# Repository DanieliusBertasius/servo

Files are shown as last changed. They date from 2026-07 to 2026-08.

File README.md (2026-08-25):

# ❗ Servo failed right after testing, suspected potentiometer wearout

Features:
* 5.75 - 12 V input
* Stall detection at 0.8 A
* Saving last servo position in flash on power down

Notes to future self:
* Add ground test points
* Use countersunk screws if screw heads mount on bottom layer, no supports needed
* Use connectors for buttons

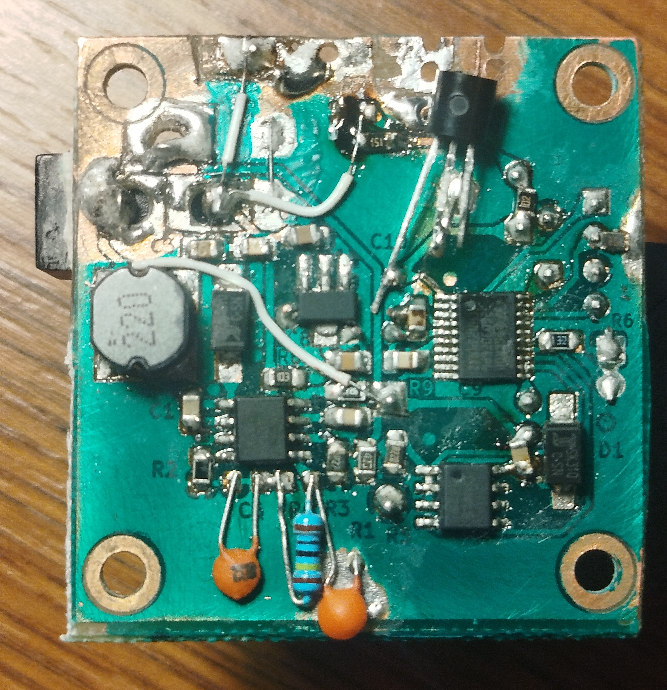
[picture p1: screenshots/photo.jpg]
Finished PCB photo


PSU: <br><br>
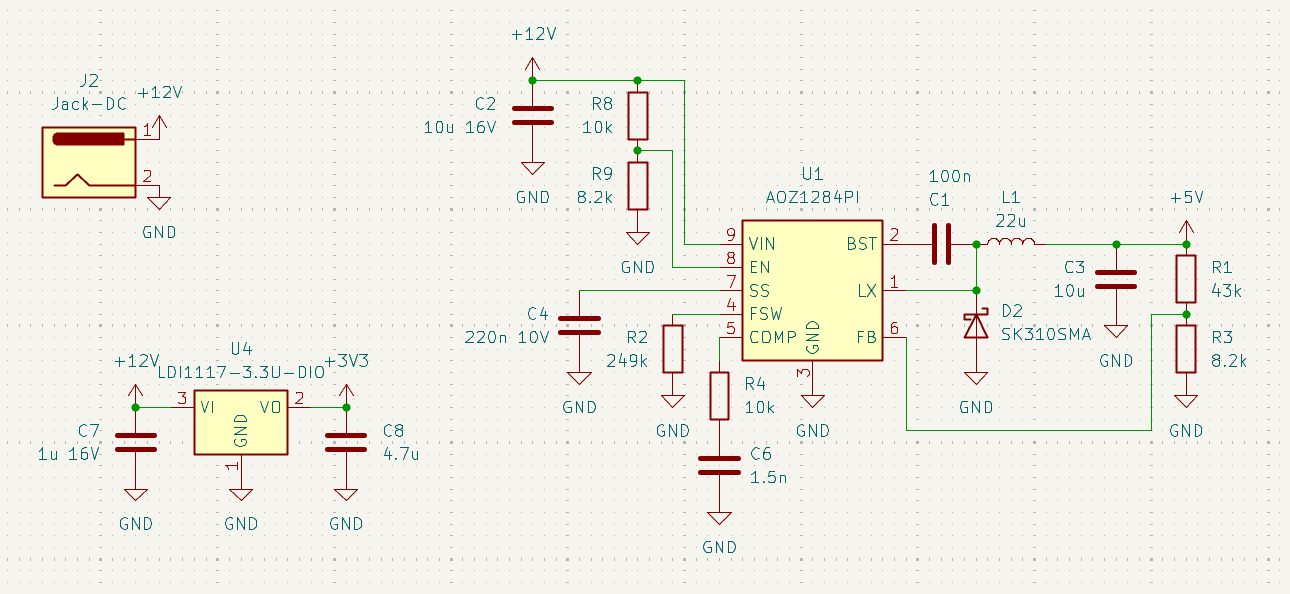
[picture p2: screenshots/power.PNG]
Power schematic


MCU: <br><br>
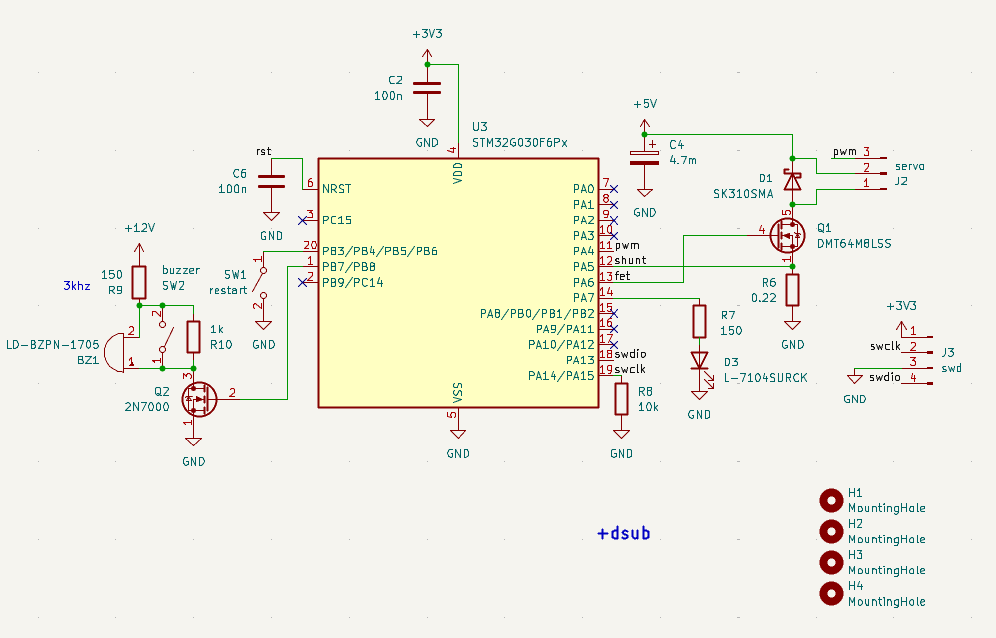
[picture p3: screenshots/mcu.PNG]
MCU schematic

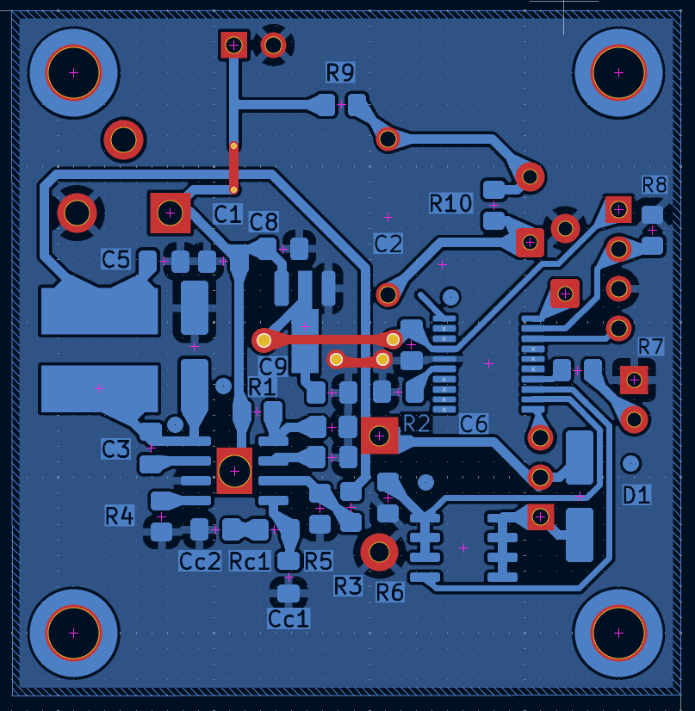
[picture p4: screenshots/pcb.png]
PCB

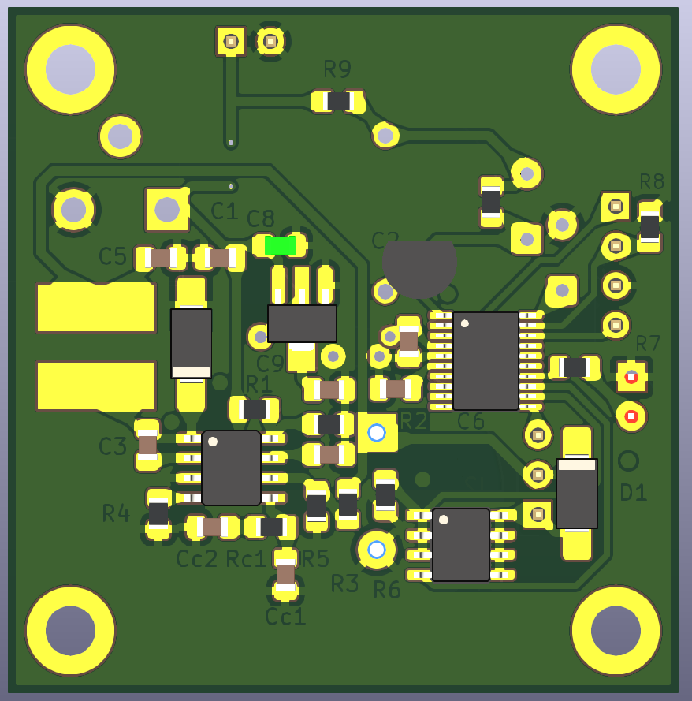
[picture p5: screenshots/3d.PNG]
3D view

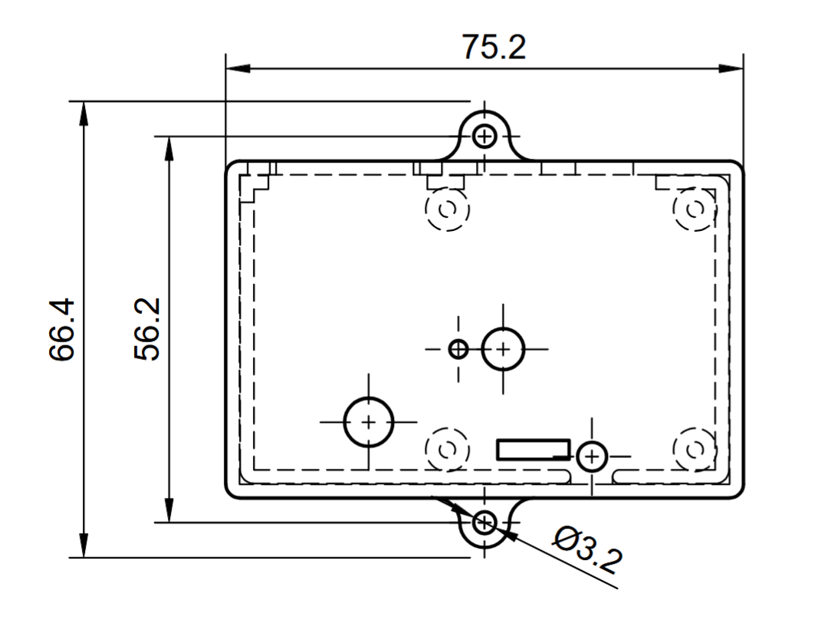
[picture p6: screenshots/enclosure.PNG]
enclosure drawing


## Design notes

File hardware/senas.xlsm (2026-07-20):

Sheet: User Guide
 | EZbuck Design Sheet Directions |  |  | Rev.1.0
The spreadsheet was design to help quickly implement the AOZ1284PI EZbuck controllers in a DC/DC converter using a buck converter.
The spreadsheet requires Iteration to be enabled to operate correctly.This is done through"Tools/Options/Calculation, select "Iteration", set the "Maximum iteration" to"1000" and the "Maximum change" to"0.0001".
The design tool will generate a recommended design that includes the loop compensation parameters and the calculated efficiency.The recommended values in the design may not be practical, yet the operation of the converter can be altered by using the closest parameter.
Input converter parameters: |  | Select buck regulator IC: | Pick the IC you want to design with.
 |  | Input voltage: | Which is converter input voltage.
 |  | Output voltage: | Which is converter output voltage.
 |  | Maximum output current: | Which is converter maximum output current.
 |  | Maximum output voltage ripple%: | Which is the output voltage ripple ratio.
 |  | Ambient temperature: | Which is the converter ambient temperature.
To use the design tool, enter data in the cells with the yellow text, the calculated values are in the cells with blue text. Red font indicate illegal input or potential design problems.

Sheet: EZBuck design calculator
7
EZBuck Design Spreadsheet |  | Rev. 1.0
Yellow cell | is the input parameters
Blue cell | is the calculated parameters
 | is the cell with comment |  | Step1: Buck regulator IC selection
 |  |  | 4
Typical application schematic
 |  |  | Step2: Define the system specification
 |  |  | Enter Application Parameters
 |  |  | Input Voltage: | 12 | V
 |  |  | Output Voltage: | 5 | V
 |  |  | Maximum Output Current: | 0.8 | A
 |  |  | Maximum Output Voltage Ripple%: | 3 | %
 |  |  | Ambient Temperature | 25 | ℃
 |  |  | Step3: RF selection
 |  |  | Switching Frequency needed: | 200 | kHz
 |  |  | Rcommend value for RF : | 250 | kΩ
 |  |  | Step4: Power stage component selection
 |  |  | Inductor Selection (L1)
 |  |  | Recommended L: | 10.42 | µH
 |  |  | Recommended ISATURATE: | 6.00 | A
 |  |  | Enter The Chosen Inductor Value: | 22 | µH
 |  |  | Enter The DCR of Chosen Inductor: | 100 | mΩ
 |  |  | Diode Selection (D1)
 |  |  | Enter The Diode Saturation Voltage: | 0.4 | V
Calculated Efficiency vs Load Current |  |  | Capacitor Selection (CIN and CO)
 |  |  | Minimum Recommended Input Capacitance: | 22 | µF
 |  |  | Minimum Input Capacitor RMS current rating: | 0.39 | Arms
 |  |  | Minimum Recommended Output Capacitance: | 2.761994949 | µF
 |  |  | Maximum Output Capacitor ESR: | 226.2857143 | mΩ
 |  |  | Enter The chosen Output Capacitor Value: | 1500 | µF
 |  |  | Enter The chosen Output Capacitor ESR: | 177 | mΩ
 |  |  | Output Voltage Characteristics
 |  |  | Estimated Output Voltage Ripple: | 117.6057449 | mV
 |  |  | Step5: Control component selection
 |  |  | Feedback Resistors Selection(RFB1, RFB2)
 |  |  | Enter a Value for RFB2: | 10 | kΩ
 |  |  | Recommended Value for RFB1: | 52.5 | kΩ
 |  |  | Compensation Component Selection (RC, CC1, CC2)
 |  |  | Enter Desired Crossover Frequency: | 20 | kHz
Calculated Bode Plot |  |  | Recommended Value for CC1: | 2.704275495 | nF
 |  |  | Recommended Value for RC: | 963.2012175 | kΩ
 |  |  | Recommended Value for CC2: | 265.6433393 | pF
 |  |  | Recommend Value for Cfeedforward: | 218.5731909 | pF
 |  |  | Enter The Chosen Value for CC1: | 2.7 | nF
 |  |  | Enter The Chosen Value for RC: | 963 | kΩ
 |  |  | Enter The Chosen Value for CC2: | 265 | pF
 |  |  | Enter The Chosen Value for Cfeedforward: | 220 | pF
 |  |  | Loop Characteristics
 |  |  | Expected Crossover Frequency: | 34.674 | kHz
 |  |  | Expected Phase Margin: | 70.22653881 | °
 |  |  | Step6: Thermal Performance
 |  |  | Thermal Characteristics
 |  |  | Internal Power Dissipation: | 0.04050994562 | W
 |  |  | Junction Temperature: | 27.51161663 | ℃
 |  |  | For datasheets,evaluation note,please visit: www.aosmd.com (http://www.aosmd.com/web/products/poweric.jsp)

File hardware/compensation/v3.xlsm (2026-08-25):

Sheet: User Guide
 | EZbuck Design Sheet Directions |  |  | Rev.1.0
The spreadsheet was design to help quickly implement the AOZ1284PI EZbuck controllers in a DC/DC converter using a buck converter.
The spreadsheet requires Iteration to be enabled to operate correctly.This is done through"Tools/Options/Calculation, select "Iteration", set the "Maximum iteration" to"1000" and the "Maximum change" to"0.0001".
The design tool will generate a recommended design that includes the loop compensation parameters and the calculated efficiency.The recommended values in the design may not be practical, yet the operation of the converter can be altered by using the closest parameter.
Input converter parameters: |  | Select buck regulator IC: | Pick the IC you want to design with.
 |  | Input voltage: | Which is converter input voltage.
 |  | Output voltage: | Which is converter output voltage.
 |  | Maximum output current: | Which is converter maximum output current.
 |  | Maximum output voltage ripple%: | Which is the output voltage ripple ratio.
 |  | Ambient temperature: | Which is the converter ambient temperature.
To use the design tool, enter data in the cells with the yellow text, the calculated values are in the cells with blue text. Red font indicate illegal input or potential design problems.

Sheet: EZBuck design calculator
7
EZBuck Design Spreadsheet |  | Rev. 1.0
Yellow cell | is the input parameters
Blue cell | is the calculated parameters
 | is the cell with comment |  | Step1: Buck regulator IC selection
 |  |  | 4
Typical application schematic
 |  |  | Step2: Define the system specification
 |  |  | Enter Application Parameters
 |  |  | Input Voltage: | 12 | V
 |  |  | Output Voltage: | 6 | V
 |  |  | Maximum Output Current: | 0.8 | A
 |  |  | Maximum Output Voltage Ripple%: | 3 | %
 |  |  | Ambient Temperature | 25 | ℃
 |  |  | Step3: RF selection
 |  |  | Switching Frequency needed: | 200 | kHz
 |  |  | Rcommend value for RF : | 250 | kΩ
 |  |  | Step4: Power stage component selection
 |  |  | Inductor Selection (L1)
 |  |  | Recommended L: | 10.71 | µH
 |  |  | Recommended ISATURATE: | 6.00 | A
 |  |  | Enter The Chosen Inductor Value: | 22 | µH
 |  |  | Enter The DCR of Chosen Inductor: | 100 | mΩ
 |  |  | Diode Selection (D1)
 |  |  | Enter The Diode Saturation Voltage: | 0.4 | V
Calculated Efficiency vs Load Current |  |  | Capacitor Selection (CIN and CO)
 |  |  | Minimum Recommended Input Capacitance: | 22 | µF
 |  |  | Minimum Input Capacitor RMS current rating: | 0.40 | Arms
 |  |  | Minimum Recommended Output Capacitance: | 2.367424242 | µF
 |  |  | Maximum Output Capacitor ESR: | 264 | mΩ
 |  |  | Enter The chosen Output Capacitor Value: | 4700 | µF
 |  |  | Enter The chosen Output Capacitor ESR: | 1 | mΩ
 |  |  | Output Voltage Characteristics
 |  |  | Estimated Output Voltage Ripple: | 0.7724854932 | mV
 |  |  | Step5: Control component selection
 |  |  | Feedback Resistors Selection(RFB1, RFB2)
 |  |  | Enter a Value for RFB2: | 10 | kΩ
 |  |  | Recommended Value for RFB1: | 65 | kΩ
 |  |  | Compensation Component Selection (RC, CC1, CC2)
 |  |  | Enter Desired Crossover Frequency: | 10 | kHz
Calculated Bode Plot |  |  | Recommended Value for CC1: | 6.477084914 | nF
 |  |  | Recommended Value for RC: | 1369.868621 | kΩ
 |  |  | Recommended Value for CC2: | 0 | pF
 |  |  | Recommend Value for Cfeedforward: | 925.624807 | pF
 |  |  | Enter The Chosen Value for CC1: | 6.8 | nF
 |  |  | Enter The Chosen Value for RC: | 1000 | kΩ
 |  |  | Enter The Chosen Value for CC2: | 0 | pF
 |  |  | Enter The Chosen Value for Cfeedforward: | 0 | pF
 |  |  | Loop Characteristics
 |  |  | Expected Crossover Frequency: | 7.2444 | kHz
 |  |  | Expected Phase Margin: | 55.82813413 | °
 |  |  | Step6: Thermal Performance
 |  |  | Thermal Characteristics
 |  |  | Internal Power Dissipation: | 0.04344546519 | W
 |  |  | Junction Temperature: | 27.69361884 | ℃
 |  |  | For datasheets,evaluation note,please visit: www.aosmd.com (http://www.aosmd.com/web/products/poweric.jsp)

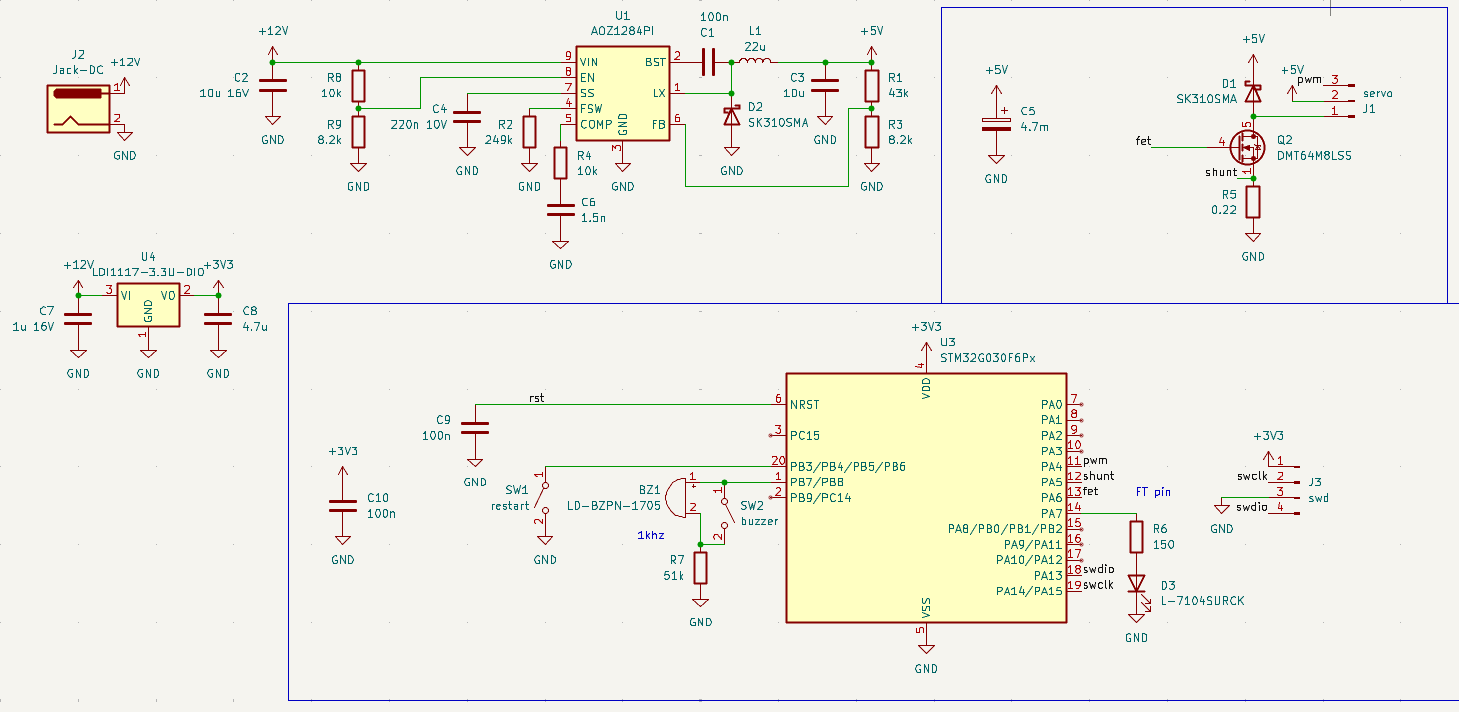
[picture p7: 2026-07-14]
hardware/schematic.png

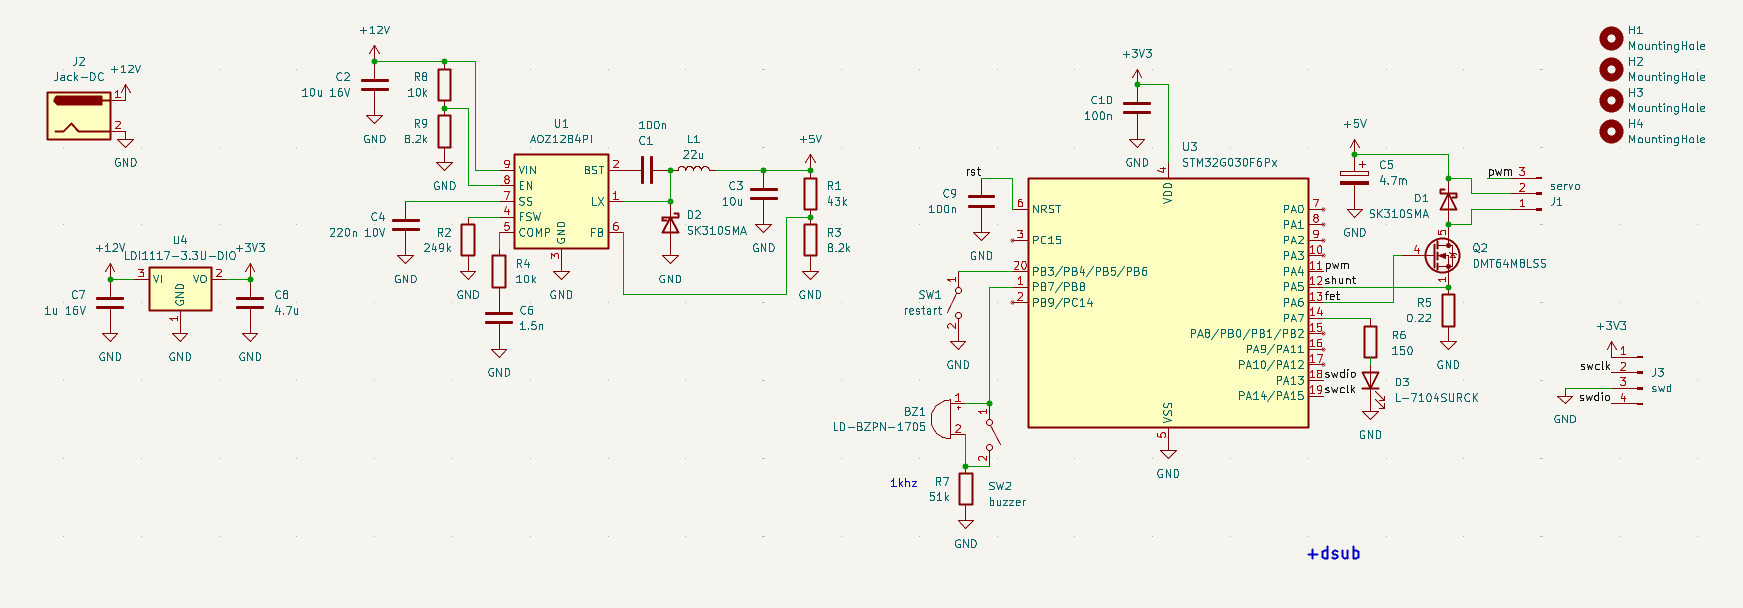
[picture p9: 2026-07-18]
screenshots/schematic.png

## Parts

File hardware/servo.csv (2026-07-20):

Id | Designator | Footprint | Quantity | Designation
1 | BZ1 | LOUDITY LD-BZPN-1705 | 1 | LD-BZPN-1705
2 | C1, C9, C10 | C_0805_2012Metric_Pad1.18x1.45mm_HandSolder | 3 | 100n
3 | C2 | C_0805_2012Metric_Pad1.18x1.45mm_HandSolder | 1 | 10u 16V
4 | C3 | C_0805_2012Metric_Pad1.18x1.45mm_HandSolder | 1 | 10u
5 | C4 | C_0805_2012Metric_Pad1.18x1.45mm_HandSolder | 1 | 220n 10V
6 | C5 | CP_Radial_D16.0mm_P7.50mm | 1 | 4.7m
7 | C6 | C_0805_2012Metric_Pad1.18x1.45mm_HandSolder | 1 | 1.5n
8 | C7 | C_0805_2012Metric_Pad1.18x1.45mm_HandSolder | 1 | 1u 16V
9 | C8 | C_0805_2012Metric_Pad1.18x1.45mm_HandSolder | 1 | 4.7u
10 | D1, D2 | D_SMA_Handsoldering | 2 | SK310SMA
11 | D3 | LED_D3.0mm | 1 | L-7104SURCK
12 | J1 | PinHeader_1x03_P2.54mm_Vertical | 1 | servo
13 | J2 | BarrelJack_CUI_PJ-102AH_Horizontal | 1 | Jack-DC
14 | J3 | PinHeader_1x04_P2.54mm_Vertical | 1 | swd
15 | L1 | LD2-220-HV | 1 | 22u
16 | Q2 | SOIC-8_3.9x4.9mm_P1.27mm | 1 | DMT64M8LSS
17 | R1 | R_0805_2012Metric_Pad1.20x1.40mm_HandSolder | 1 | 43k
18 | R2 | R_0805_2012Metric_Pad1.20x1.40mm_HandSolder | 1 | 249k
19 | R3, R9 | R_0805_2012Metric_Pad1.20x1.40mm_HandSolder | 2 | 8.2k
20 | R4, R8 | R_0805_2012Metric_Pad1.20x1.40mm_HandSolder | 2 | 10k
21 | R5 | R_0805_2012Metric_Pad1.20x1.40mm_HandSolder | 1 | 0.22
22 | R6 | R_0805_2012Metric_Pad1.20x1.40mm_HandSolder | 1 | 1.3k
23 | R7 | R_0805_2012Metric_Pad1.20x1.40mm_HandSolder | 1 | 51k
24 | SW1 | SolderWire-0.25sqmm_1x02_P4.2mm_D0.65mm_OD1.7mm | 1 | restart
25 | SW2 | SolderWire-0.25sqmm_1x02_P4.2mm_D0.65mm_OD1.7mm | 1 | buzzer
26 | U1 | SOIC-8-1EP_3.9x4.9mm_P1.27mm_EP2.71x3.7mm | 1 | AOZ1284PI
27 | U3 | TSSOP-20_4.4x6.5mm_P0.65mm | 1 | STM32G030F6Px
28 | U4 | SOT-89-3_Handsoldering | 1 | LDI1117-3.3U-DIO

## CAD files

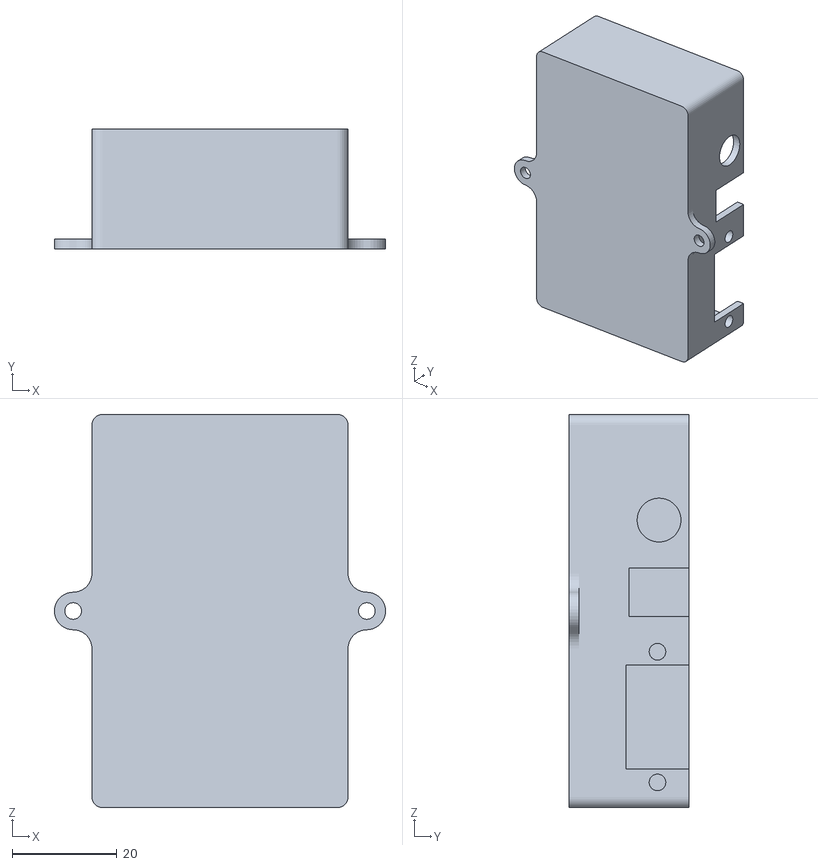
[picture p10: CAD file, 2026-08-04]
hardware/3D/bottom.stl
63.4 x 23.0 x 75.2

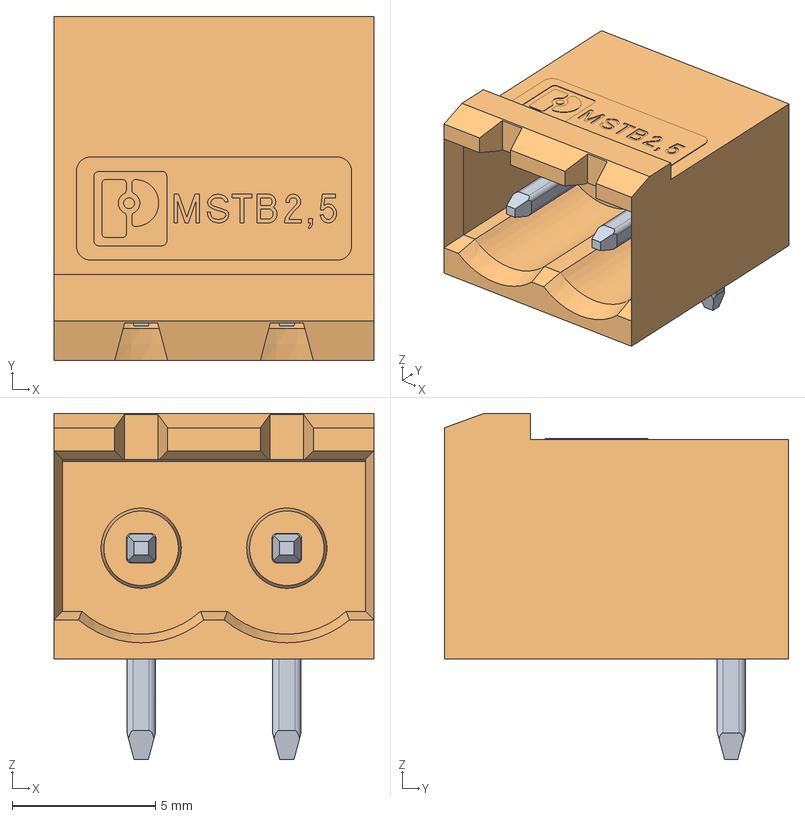
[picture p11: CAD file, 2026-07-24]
hardware/3D/for fusion assembly/terminal.step
11.2 x 12.0 x 12.1 mm

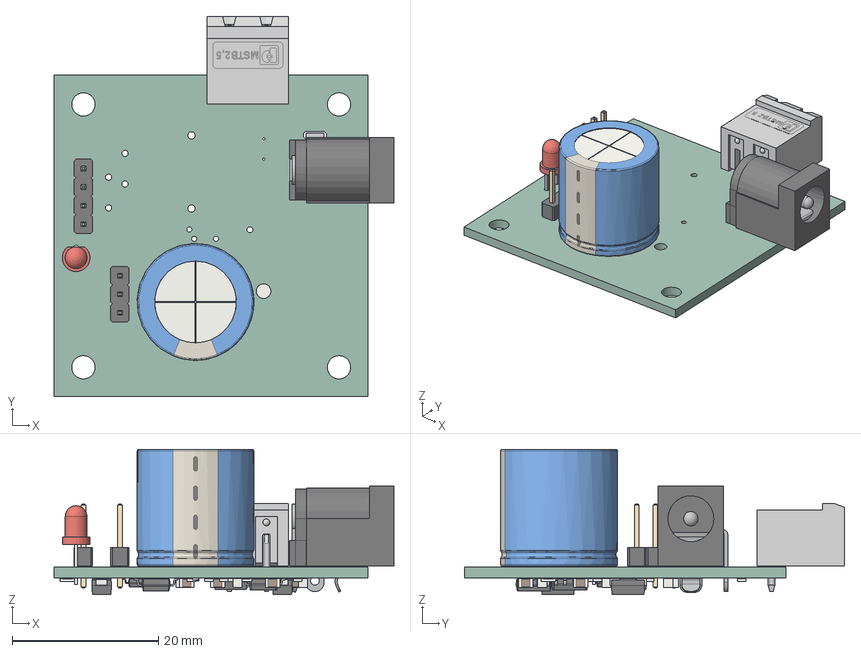
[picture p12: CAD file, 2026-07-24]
hardware/3D/for fusion assembly/pcb.step
46.5 x 52.0 x 19.9 mm
(Unsaved)
LED_D3.0mm
CP_Radial_D160mm_P750mm
PinHeader_1x04_P254mm_Vertical
PinHeader_1x03_P254mm_Vertical
BarrelJack_GCT_DCJ200-10-A_Horizontal
C_0805_2012Metric x 10
R_0805_2012Metric x 10
adbeea57-9c39-11ed-93f0-dde97e994e83_part
adbeea58-9c39-11ed-93f0-dde97e994e83_part
adbeea59-9c39-11ed-93f0-dde97e994e83_part
SOIC-8-1EP_3.9x4.9mm_P1.27mm_EP2.29x3mm
D_SMA x 2
TSSOP-20_4.4x6.5mm_P0.65mm
SOIC-8_3.9x4.9mm_P1.27mm
servo_PCB

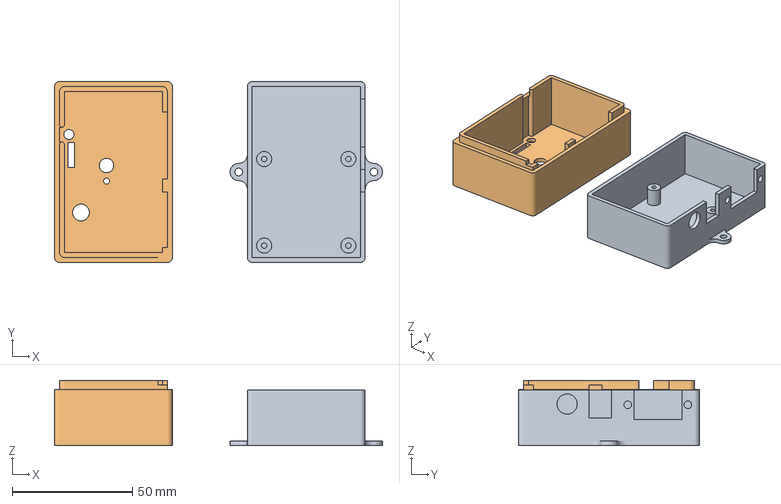
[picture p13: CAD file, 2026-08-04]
hardware/3D/servo_e3v2.3mf
136.4 x 75.2 x 27.1 mm
bottom.stl
top.stl

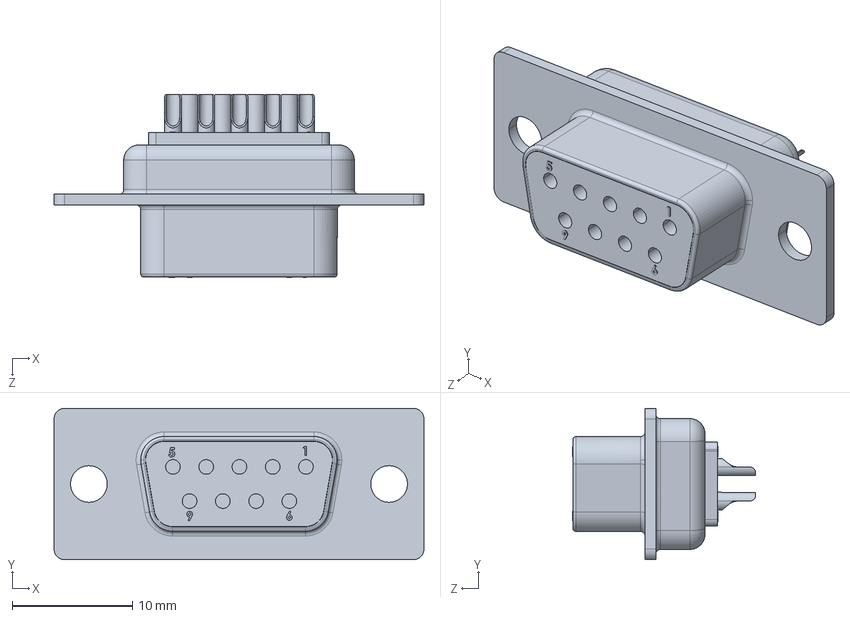
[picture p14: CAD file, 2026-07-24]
hardware/3D/for fusion assembly/dsub.STEP
30.8 x 12.6 x 15.3 mm

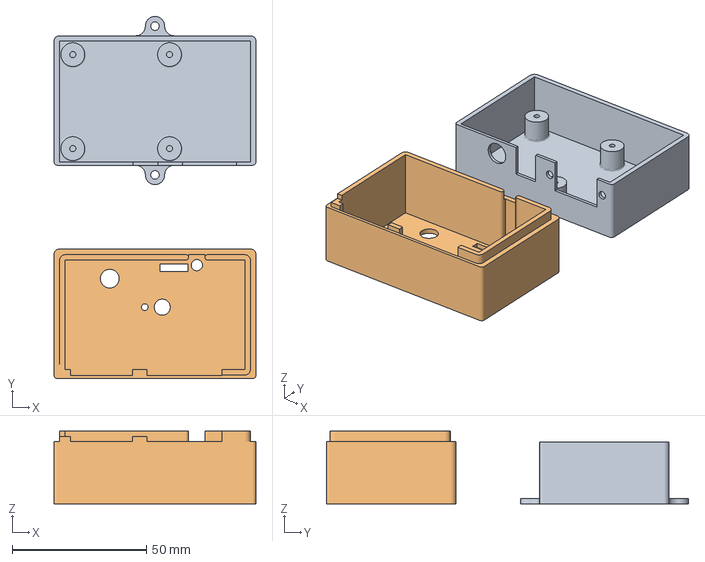
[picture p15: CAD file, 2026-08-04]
hardware/3D/servo_bambu.3mf
75.2 x 134.8 x 27.1 mm
bottom.stl
top.stl

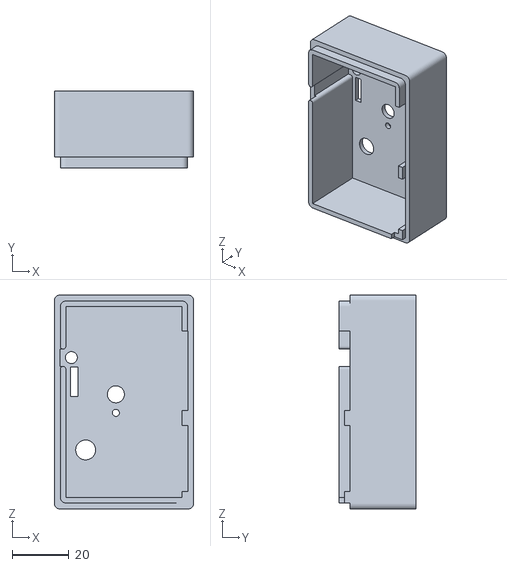
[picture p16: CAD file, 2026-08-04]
hardware/3D/top.stl
49.0 x 27.1 x 75.2

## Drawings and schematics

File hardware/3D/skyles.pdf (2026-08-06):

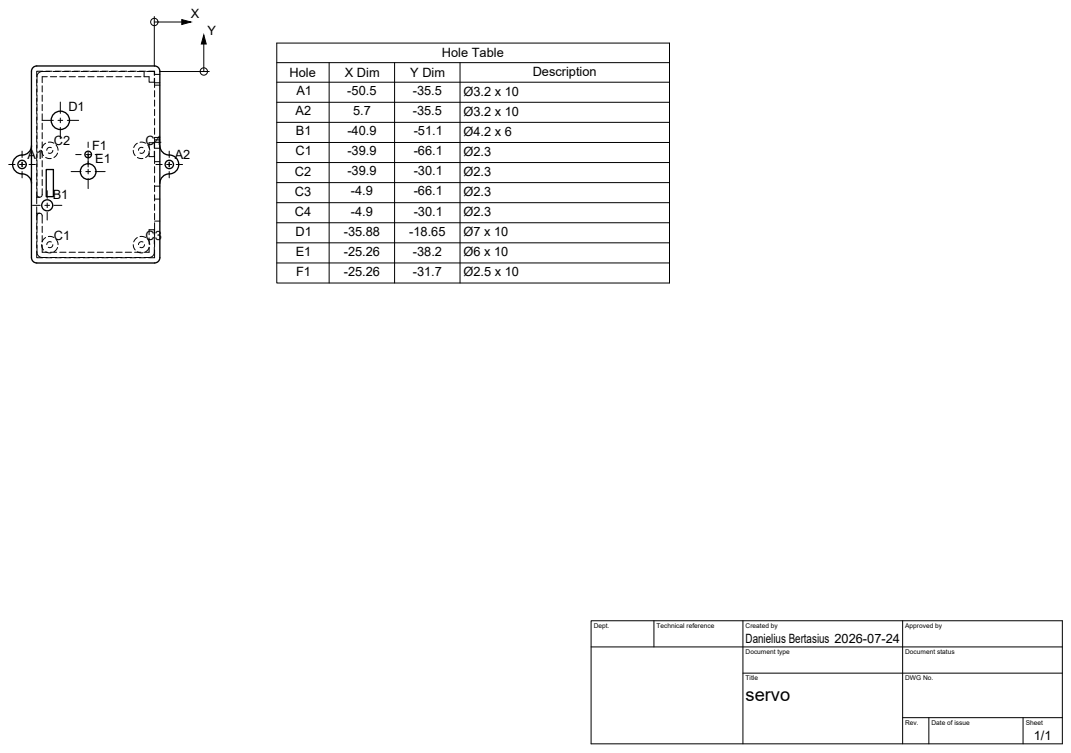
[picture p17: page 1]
Hole Table

Hole | X Dim | Y Dim | Description
A1 | -50.5 | -35.5 | Ø3.2 x 10
A2 | 5.7 | -35.5 | Ø3.2 x 10
B1 | -40.9 | -51.1 | Ø4.2 x 6
C1 | -39.9 | -66.1 | Ø2.3
C2 | -39.9 | -30.1 | Ø2.3
C3 | -4.9 | -66.1 | Ø2.3
C4 | -4.9 | -30.1 | Ø2.3
D1 | -35.88 | -18.65 | Ø7 x 10
E1 | -25.26 | -38.2 | Ø6 x 10
F1 | -25.26 | -31.7 | Ø2.5 x 10

Dept. | Technical reference | Created by Danielius Bertasius 2026-07-24 | Approved by

Document type | Document status

Title servo | DWG No.

Rev. | Date of issue | Sheet 1/1

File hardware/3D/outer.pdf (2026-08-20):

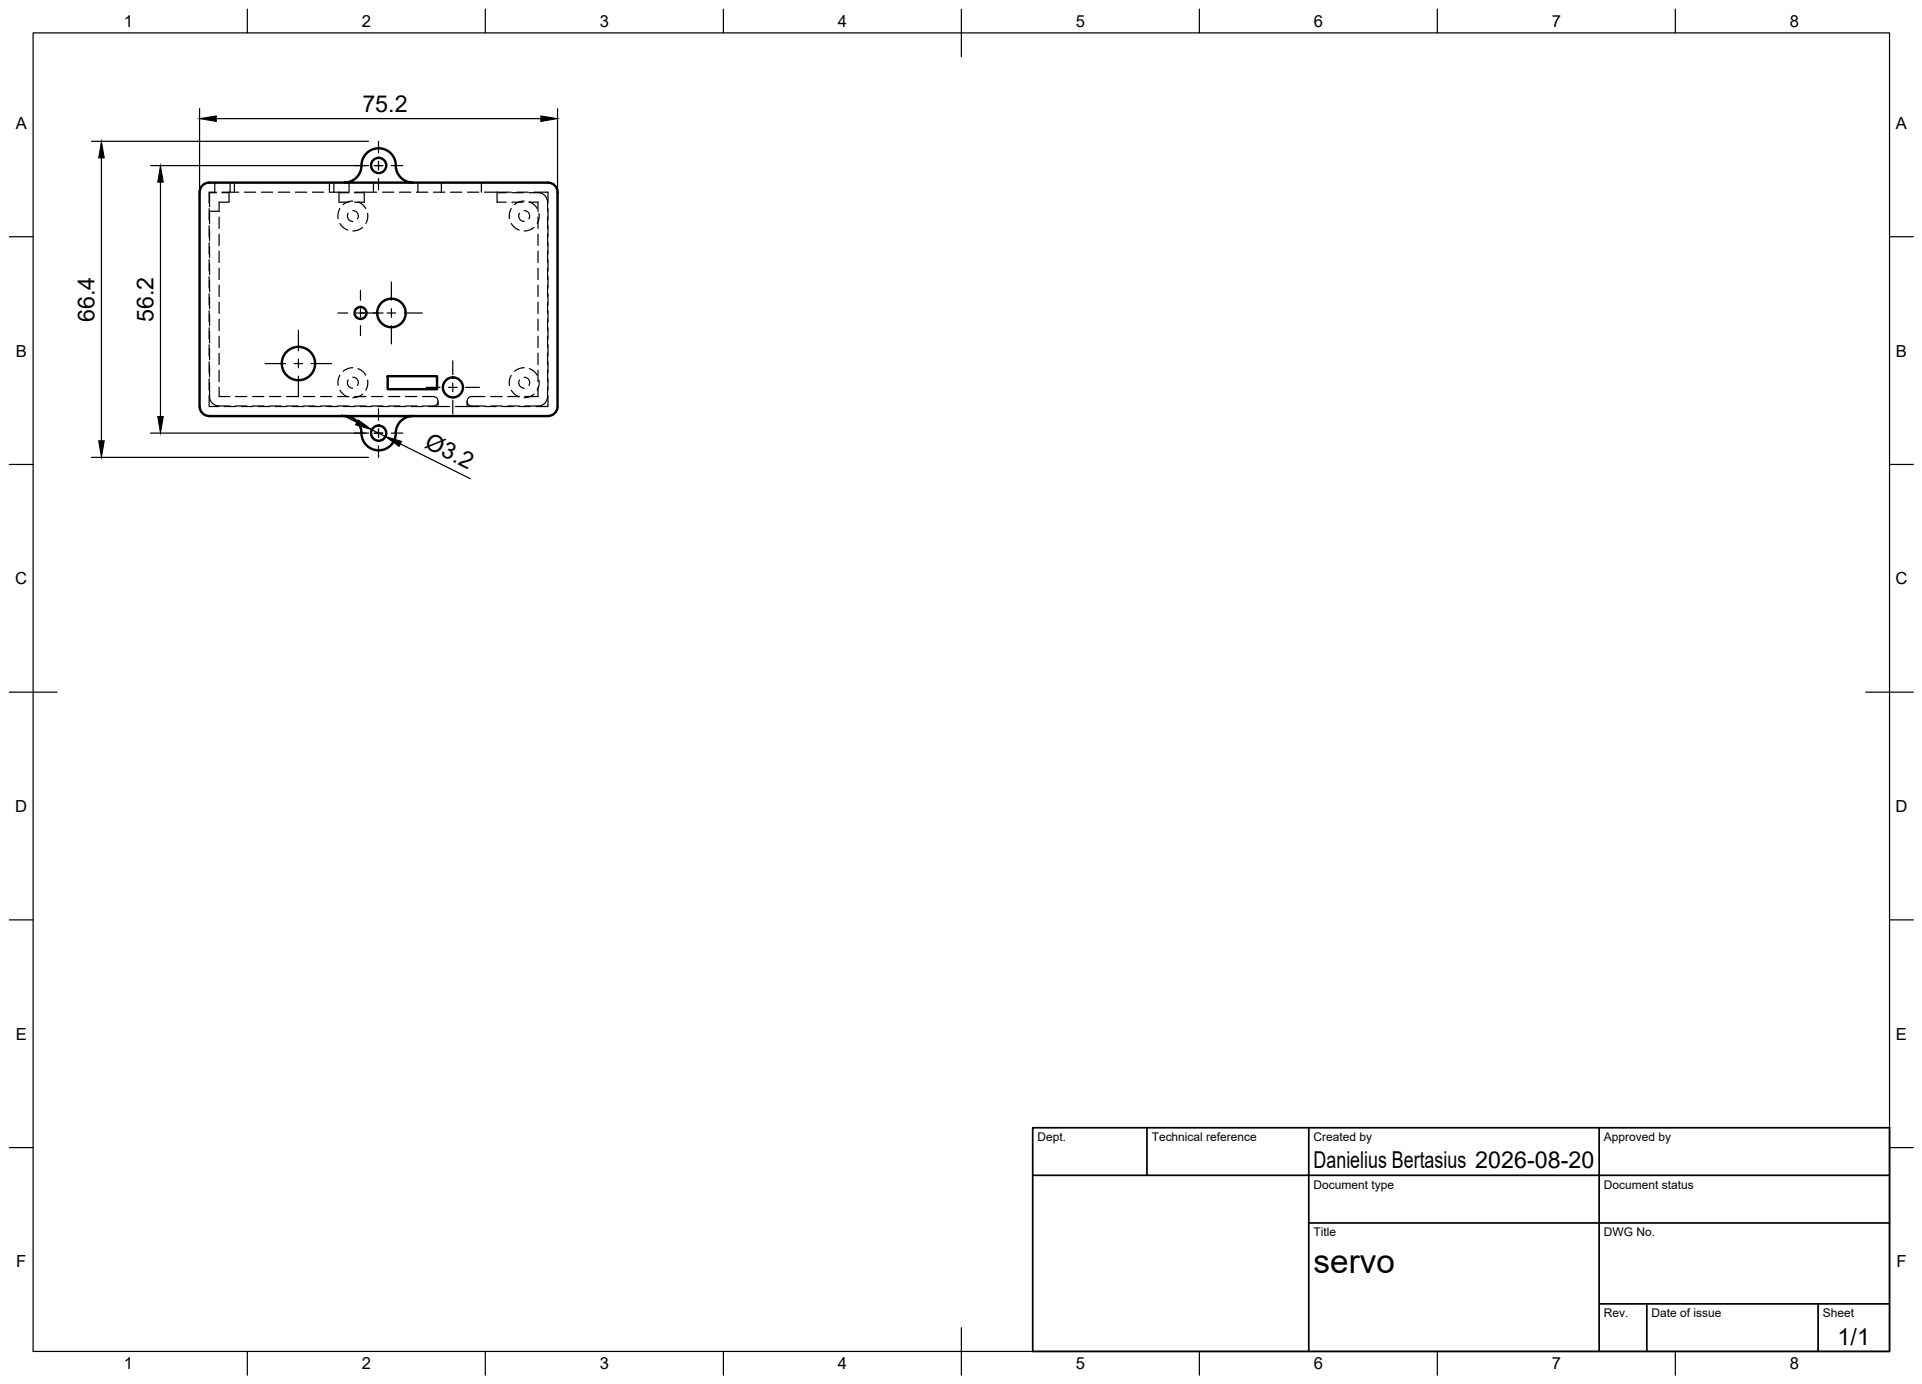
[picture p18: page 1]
Title; DWG No.; Rev.; Date of issue; Sheet; Danielius Bertasius 66.4

Dept. | Technical reference | Created by 2026-08-20 | Approved by

Document type | Document status

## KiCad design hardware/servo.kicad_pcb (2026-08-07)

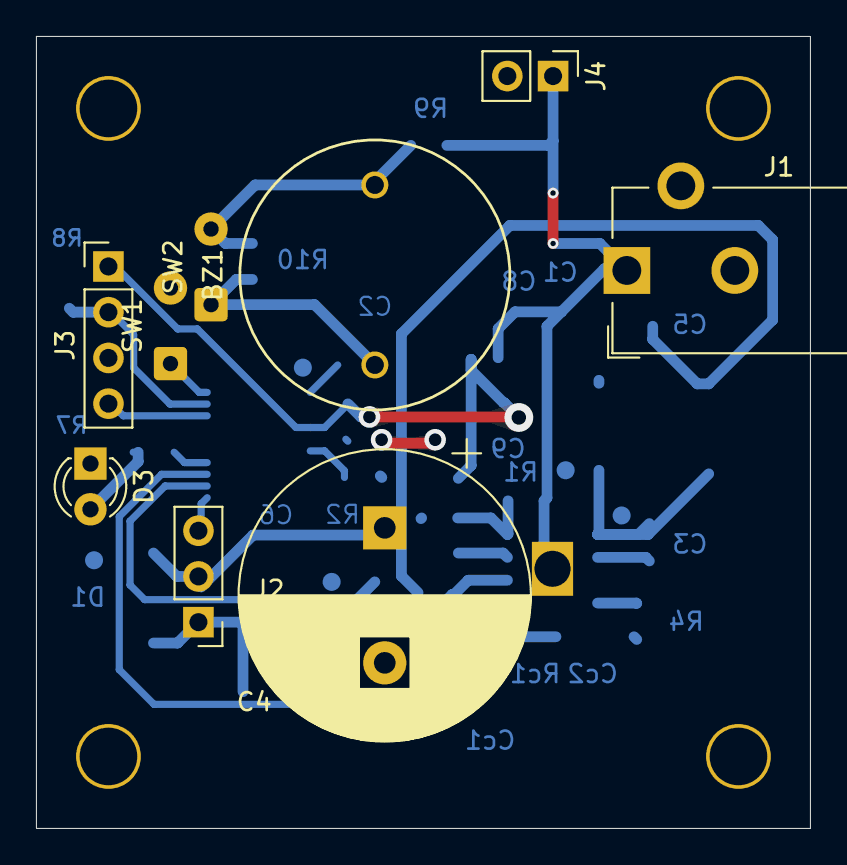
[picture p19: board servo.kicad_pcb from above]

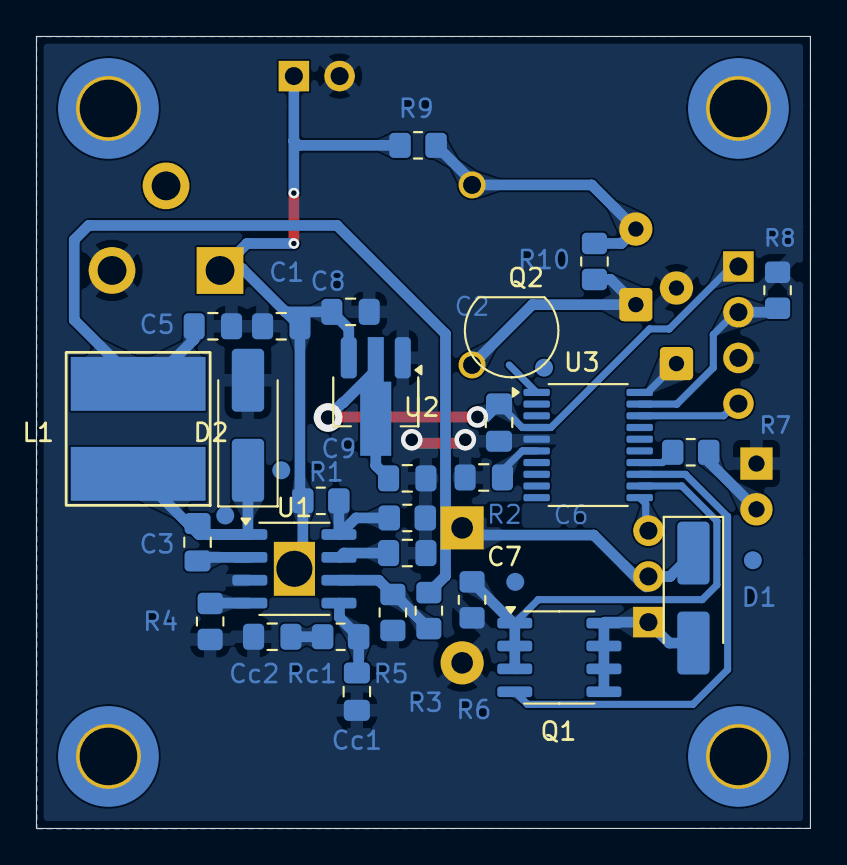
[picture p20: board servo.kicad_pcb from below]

Board: 2 copper layers, 43.0 x 44.0 mm, 42 parts (33 on the bottom side), 24 nets.

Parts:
BZ1: LD-BZPN-1705; LOUDITY LD-BZPN-1705
C1: 10u 16V; C_0805_2012Metric_Pad1.18x1.45mm_HandSolder
C2, C3, C6: 100n; C_0805_2012Metric_Pad1.18x1.45mm_HandSolder
C4: 4.7m; CP_Radial_D16.0mm_P7.50mm
C5: 10u; C_0805_2012Metric_Pad1.18x1.45mm_HandSolder
C7: 220n 10V; C_0805_2012Metric_Pad1.18x1.45mm_HandSolder
C8: 1u 16V; C_0805_2012Metric_Pad1.18x1.45mm_HandSolder
C9: 4.7u; C_0805_2012Metric_Pad1.18x1.45mm_HandSolder
Cc1: 150p; C_0805_2012Metric_Pad1.18x1.45mm_HandSolder
Cc2: 6.8n; C_0805_2012Metric_Pad1.18x1.45mm_HandSolder
D1, D2: SK310SMA; D_SMA_Handsoldering
D3: L-7104SURCK; LED_D3.0mm
H1, H2, H3, H4: MountingHole; MountingHole_3.2mm_M3_DIN965_Pad_TopOnly
J1: 5.5x2.1; BarrelJack_CUI_PJ-102AH_Horizontal
J2: servo; PinHeader_1x03_P2.54mm_Vertical
J3: swd; PinHeader_1x04_P2.54mm_Vertical
J4: LED; PinHeader_1x02_P2.54mm_Vertical
L1: 22u; LD2-HV
Q1: DMT64M8LSS; SOIC-8_3.9x4.9mm_P1.27mm
Q2: 2N7000; TO-92_Inline
R1, R8: 10k; R_0805_2012Metric_Pad1.20x1.40mm_HandSolder
R2, R5: 8.2k; R_0805_2012Metric_Pad1.20x1.40mm_HandSolder
R3: 43k; R_0805_2012Metric_Pad1.20x1.40mm_HandSolder
R4: 249k; R_0805_2012Metric_Pad1.20x1.40mm_HandSolder
R6: 0.22; R_0805_2012Metric_Pad1.20x1.40mm_HandSolder
R7: 150; R_0805_2012Metric_Pad1.20x1.40mm_HandSolder
R9: 1k; R_0805_2012Metric_Pad1.20x1.40mm_HandSolder
R10: 3k; R_0805_2012Metric_Pad1.20x1.40mm_HandSolder
Rc1: 1M; R_0805_2012Metric_Pad1.20x1.40mm_HandSolder
SW1: restart; SolderWire-0.25sqmm_1x02_P4.2mm_D0.65mm_OD1.7mm
SW2: buzzer; SolderWire-0.25sqmm_1x02_P4.2mm_D0.65mm_OD1.7mm
U1: AOZ1284PI; SOIC-8-1EP_3.9x4.9mm_P1.27mm_EP2.29x3mm_diy
U2: LDI1117-3.3U-DIO; SOT-89-3_Handsoldering
U3: STM32G030F6Px; TSSOP-20_4.4x6.5mm_P0.65mm

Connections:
+3V3: C2.1, C9.1, J3.1, U2.2 (VO), U3.4 (VDD)
+5V: C4.1, C5.1, D1.1 (K), J2.2, L1.2, R3.1
+12V: C1.1, C8.1, J1.1, J4.1, R1.1, R9.2, U1.9 (VIN), U2.3 (VI)
/fet: Q1.4 (G), U3.13 (PA6)
/pwm: J2.3, U3.11 (PA4)
/rst: C6.1, U3.6 (NRST)
/shunt: Q1.1 (S), Q1.2 (S), Q1.3 (S), R6.1, U3.12 (PA5)
/swclk: J3.2, R8.1, U3.19 (PA14/PA15)
/swdio: J3.4, U3.18 (PA13)
GND: C1.2, C2.2, C4.2, C5.2, C6.2, C7.2, C8.2, C9.2, Cc1.2, Cc2.2, D2.2 (A), D3.1 (K), J1.2, J3.3, J4.2, R2.2, R4.2, R5.2, R6.2, R8.2, SW1.2 (B), U1.3 (GND), U2.1 (GND), U3.5 (VSS)
unnamed: BZ1.1 (+), R10.1, SW2.1 (A)
unnamed: BZ1.2 (-), R9.1, R10.2, SW2.2 (B)
unnamed: Cc2.1, Rc1.2
unnamed: D1.2 (A), J2.1, Q1.5 (D), Q1.6 (D), Q1.7 (D), Q1.8 (D)
unnamed: C3.2, D2.1 (K), L1.1, U1.1 (LX)
unnamed: D3.2 (A), R7.2
unnamed: SW1.1 (A), U3.20 (PB3/PB4/PB5/PB6)
unnamed: C3.1, U1.2 (BST)
unnamed: Cc1.1, Rc1.1, U1.5 (COMP)
unnamed: R1.2, R2.1, U1.8 (EN)
unnamed: R3.2, R5.1, U1.6 (FB)
unnamed: R4.1, U1.4 (FSW)
unnamed: C7.1, U1.7 (SS)
unnamed: R7.1, U3.14 (PA7)

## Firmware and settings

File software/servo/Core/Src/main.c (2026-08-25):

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
/* Includes ------------------------------------------------------------------*/
#include "main.h"

/* USER CODE BEGIN PD */
#define BUZZER 250 // modulation half period in millis

#define VREFINT 1.212
#define POWEROFF_THRESHOLD VREFINT/3.05*4095

#define I_STALL 0.8
#define R_SHUNT 0.22
#define THRESHOLD I_STALL*R_SHUNT/3.3*4095
#define ARRAY (20*30) //30 is one servo update period, 5*30 optimal
#define SPEED 3 //increment in degrees every 10ms

#define DEBOUNCE 500

#define SOFTSTART 100
#define ADC_DELAY 100
#define ADCSTART0 (SOFTSTART+ADC_DELAY)

#define FLASH_ADDR   0x08007800U
#define FLASH_PAGE   15U
/* USER CODE END PD */

ADC_HandleTypeDef hadc1;
DMA_HandleTypeDef hdma_adc1;

TIM_HandleTypeDef htim14;
TIM_HandleTypeDef htim16;

/* USER CODE BEGIN PV */
volatile uint8_t servo_power_rdy=0,angle=90,direction=1,stall=0,adc=0,ticked=0,stop_command=0,pressed=0,complete=0,
		write_command=0,go_home=0,interrupts=1;
uint8_t empty_found=0,buzzer=0;
volatile uint16_t ADC_VAL[ARRAY],sum=0;
uint16_t current=0,current2=0;
volatile uint32_t last_debounce=0,tick=0,restart=0;
uint32_t next_write=FLASH_ADDR;

/* USER CODE END PV */

void SystemClock_Config(void);
static void MX_GPIO_Init(void);
static void MX_DMA_Init(void);
static void MX_ADC1_Init(void);
static void MX_TIM14_Init(void);
static void MX_TIM16_Init(void);
/* USER CODE BEGIN PFP */
HAL_StatusTypeDef Erase_Flash_Page(uint32_t page_num);
HAL_StatusTypeDef Write_Flash(uint32_t address, uint8_t value);
/* USER CODE END PFP */

/**
  * @brief  The application entry point.
  * @retval int
  */
int main(void)
{

  /* MCU Configuration--------------------------------------------------------*/

  /* Reset of all peripherals, Initializes the Flash interface and the Systick. */
  HAL_Init();

  /* Configure the system clock */
  SystemClock_Config();

  /* Initialize all configured peripherals */
  MX_GPIO_Init();
  MX_DMA_Init();
  MX_ADC1_Init();
  MX_TIM14_Init();
  MX_TIM16_Init();
  /* USER CODE BEGIN 2 */
  for(uint32_t i=FLASH_ADDR;i<(FLASH_ADDR+2048U);i+=8){
	  if(*(volatile uint64_t*)i!=0xFFFFFFFFFFFFFFFFULL){
		  angle = *(volatile uint8_t*)i;
	  }
	  else{
		  next_write=i;
		  empty_found=1;
		  break;
	  }
  }
  if(empty_found==0){
	  Erase_Flash_Page(FLASH_PAGE);
	  next_write=FLASH_ADDR;
  }
  HAL_TIM_Base_Start_IT(&htim16);
  TIM14->CCR1 = (angle/180.0*0.09+0.03)*65535;
  HAL_TIM_Base_Start_IT(&htim14);
  HAL_TIM_PWM_Start(&htim14, TIM_CHANNEL_1);
  /* USER CODE END 2 */

  /* Infinite loop */
  /* USER CODE BEGIN WHILE */
  while(1){
	if(pressed){
		pressed=0;
		if(stall){
			stall=0;
			restart=HAL_GetTick();
			HAL_GPIO_WritePin(fet_GPIO_Port, fet_Pin, 1);
			HAL_TIM_PWM_Start(&htim14, TIM_CHANNEL_1); //servo write
			HAL_GPIO_WritePin(led_GPIO_Port, led_Pin, 0);
		}
		else{
			go_home++;
		}
	}
	if(ticked){
		ticked=0;
		tick=HAL_GetTick();
		if(tick%1000<10){
			current2=current;
		}
		if(tick%BUZZER==0){
			buzzer=!buzzer;
		}
		if(restart==0 && tick>=ADCSTART0 && adc==0){ // only at bootup
			HAL_ADC_Start_DMA(&hadc1, (uint32_t*)&ADC_VAL, ARRAY); // always first in systick
			adc=1;
		}
		else if(restart!=0 && tick>=restart+ADC_DELAY && adc==0){
			HAL_ADC_Start_DMA(&hadc1, (uint32_t*)&ADC_VAL, ARRAY); // always first in systick
			adc=1;
		}
		if(tick>last_debounce+DEBOUNCE && interrupts==0){
		    __HAL_GPIO_EXTI_CLEAR_FALLING_IT(GPIO_PIN_3);
		    HAL_NVIC_ClearPendingIRQ(EXTI2_3_IRQn);
			HAL_NVIC_EnableIRQ(EXTI2_3_IRQn);
			interrupts=1;
		}
		if(servo_power_rdy==0&&tick>=SOFTSTART){
			servo_power_rdy=1;
		}

		if(servo_power_rdy&&stall==0&&tick%10==0&&write_command==0){
			switch(go_home){
				case 0:
					if(angle==180){
						direction=0;
					}
					else if(angle==0){
						direction=1;
					}
					if(direction){
						angle+=SPEED;
					}
					else{
						angle-=SPEED;
					}
					break;
				case 1:
					if(angle==180||angle==0){
						break;
					}
					if(direction){
						angle+=SPEED;
					}
					else{
						angle-=SPEED;
					}
					break;
				case 2:
					if(angle==0){
						direction=1;
					}
					else if(angle==180){
						direction=0;
					}
					else if(angle==90){
						break;
					}
					if(direction){
						angle+=SPEED;
					}
					else{
						angle-=SPEED;
					}
					break;
				default:
					go_home=0;
					break;
			}
		}
		if(stall){
			HAL_ADC_Stop_DMA(&hadc1); // stop sampling for stalls & position
			HAL_TIM_PWM_Stop(&htim14, TIM_CHANNEL_1); // servo control stop
			HAL_GPIO_WritePin(fet_GPIO_Port, fet_Pin, 0); // servo power cut
			adc=0;
			HAL_GPIO_WritePin(led_GPIO_Port, led_Pin, 1); // alert LED on
		}
		TIM14->CCR1 = (angle/180.0*0.094+0.028)*65535;

		if(complete){
			HAL_ADC_Stop_DMA(&hadc1);
			complete=0;
			int i;
			for(i=0;i<ARRAY;i+=2){
				sum+=ADC_VAL[i];
			}
			sum=sum/ARRAY*2;
			current=sum/4095.0*3.3/R_SHUNT*1e3;
			if(sum>THRESHOLD){
				stall=1;
			}
			else if(stall==0){
				HAL_ADC_Start_DMA(&hadc1, (uint32_t*)&ADC_VAL, ARRAY);
			}
			sum=0;
		}

	}

    /* USER CODE END WHILE */

    /* USER CODE BEGIN 3 */
  }
  /* USER CODE END 3 */
}

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
/* USER CODE BEGIN 4 */
HAL_StatusTypeDef Erase_Flash_Page(uint32_t page_num){
    HAL_StatusTypeDef status;
    uint32_t page_error = 0;
    HAL_FLASH_Unlock();

    __HAL_FLASH_CLEAR_FLAG(FLASH_FLAG_OPERR);
    __HAL_FLASH_CLEAR_FLAG(FLASH_FLAG_PROGERR);
    __HAL_FLASH_CLEAR_FLAG(FLASH_FLAG_WRPERR);
    __HAL_FLASH_CLEAR_FLAG(FLASH_FLAG_PGAERR);
    __HAL_FLASH_CLEAR_FLAG(FLASH_FLAG_SIZERR);
    __HAL_FLASH_CLEAR_FLAG(FLASH_FLAG_PGSERR);
    __HAL_FLASH_CLEAR_FLAG(FLASH_FLAG_MISERR);
    __HAL_FLASH_CLEAR_FLAG(FLASH_FLAG_FASTERR);
    __HAL_FLASH_CLEAR_FLAG(FLASH_FLAG_OPTVERR);

    // 3. Configure page erase parameters
    FLASH_EraseInitTypeDef eraseConfig = {0};
    eraseConfig.TypeErase   = FLASH_TYPEERASE_PAGES;
    eraseConfig.Banks       = FLASH_BANK_1;
    eraseConfig.Page        = page_num;
    eraseConfig.NbPages     = 1;

    status = HAL_FLASHEx_Erase(&eraseConfig, &page_error);
    HAL_FLASH_Lock();
    return status;
}
HAL_StatusTypeDef Write_Flash(uint32_t address, uint8_t value){
    HAL_StatusTypeDef status;
    HAL_FLASH_Unlock();

    __HAL_FLASH_CLEAR_FLAG(FLASH_FLAG_OPERR);
    __HAL_FLASH_CLEAR_FLAG(FLASH_FLAG_PROGERR);
    __HAL_FLASH_CLEAR_FLAG(FLASH_FLAG_WRPERR);
    __HAL_FLASH_CLEAR_FLAG(FLASH_FLAG_PGAERR);
    __HAL_FLASH_CLEAR_FLAG(FLASH_FLAG_SIZERR);
    __HAL_FLASH_CLEAR_FLAG(FLASH_FLAG_PGSERR);
    __HAL_FLASH_CLEAR_FLAG(FLASH_FLAG_MISERR);
    __HAL_FLASH_CLEAR_FLAG(FLASH_FLAG_FASTERR);
    __HAL_FLASH_CLEAR_FLAG(FLASH_FLAG_OPTVERR);

    status = HAL_FLASH_Program(FLASH_TYPEPROGRAM_DOUBLEWORD, address, value);
    HAL_FLASH_Lock();
    return status;
}

void HAL_ADC_ConvCpltCallback(ADC_HandleTypeDef* hadc)
{
	complete=1;
	if(ADC_VAL[1]>POWEROFF_THRESHOLD){
		write_command=1;
		HAL_TIM_PWM_Stop(&htim14, TIM_CHANNEL_1); // servo control stop
		HAL_GPIO_WritePin(fet_GPIO_Port, fet_Pin, 0); // servo power cut
		if(Write_Flash(next_write, angle)==HAL_OK){
			HAL_GPIO_WritePin(led_GPIO_Port, led_Pin, 1);
		}
	}
}
void HAL_GPIO_EXTI_Falling_Callback(uint16_t GPIO_Pin){
	HAL_NVIC_DisableIRQ(EXTI2_3_IRQn);
	interrupts=0;
	last_debounce=HAL_GetTick();
	pressed=1;
}
void HAL_TIM_PeriodElapsedCallback(TIM_HandleTypeDef* htim){
	if(htim->Instance == TIM16){
		if(stall&&buzzer){
			HAL_GPIO_TogglePin(buzzer_GPIO_Port, buzzer_Pin);
		}
		else{
			HAL_GPIO_WritePin(buzzer_GPIO_Port, buzzer_Pin, 0);
		}
	}
}
/* USER CODE END 4 */
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


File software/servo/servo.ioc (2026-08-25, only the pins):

Mcu.UserName=STM32G030F6Px
PA13.Signal=SYS_SWDIO
PA14-BOOT0.Signal=SYS_SWCLK
PA4.Signal=S_TIM14_CH1
PA5.Signal=ADC1_IN5
PA6.GPIO_Label=fet
PA6.Signal=GPIO_Output
PA7.GPIO_Label=led
PA7.Signal=GPIO_Output
PB3.Signal=GPXTI3
PB7.GPIO_Label=buzzer
PB7.Signal=GPIO_Output

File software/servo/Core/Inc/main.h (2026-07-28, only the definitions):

#define buzzer_Pin GPIO_PIN_7
#define buzzer_GPIO_Port GPIOB
#define fet_Pin GPIO_PIN_6
#define fet_GPIO_Port GPIOA
#define led_Pin GPIO_PIN_7
#define led_GPIO_Port GPIOA

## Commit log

2026-07-18 clean up schematic
    [servo.kicad_sch]
2026-07-18 add NC flags, update README
    [servo.kicad_sch]
2026-07-20 Increase ADC delay
    Increase ADC delay to ignore motor inrush
2026-07-20 Add DC-DC calculator
    [Worksheet in EZBuckDesignTool-20230516.xlsm, senas.xlsm, servo.csv]
2026-07-24 Fix false stall detection after restart
    [servo.kicad_pcb, servo.kicad_sch]
2026-07-27 Remove 3D print project & gcode
    Too low first layer height; overextrusion
    [servo_ender.3mf]
2026-07-27 Add stall detection filtering
    [main.c, main.h, servo.ioc]
2026-07-28 Restore file changes for pull request
    [servo_ender.3mf]
2026-07-28 Add servo angle write to flash on poweroff
2026-07-30 Fix stall detection
2026-07-31 Rename fusion assembly folder
    [dsub.STEP]
2026-07-31 edit fusion assembly folder name
    [dsub.STEP]
2026-07-31 Update PCB for v2
    [servo.kicad_pcb]
2026-07-31 Update PCB
    [servo.kicad_pcb]
2026-08-04 Update enclosure
    Put connectors on one side of enclosure, adjust spacing, add friction fit, use barrel jack instead of terminal
    [bottom.stl, servo_bambu.3mf, servo_bambu.gcode.3mf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]
2026-08-04 Add Ender 3 v2 project & gcode, minor fixes, clean up
    [bottom.stl, servo_bambu.gcode.3mf, servo_e3v2.3mf]
2026-08-06 Add stall detection demo, change buzzer freq, readability
    [main.c, servo.ioc]
2026-08-07 Change buzzer supply to 12V, update PCB
    [servo.kicad_pcb, servo.kicad_sch]
2026-08-07 Move footprint for v2
    [servo.kicad_pcb]
2026-08-07 Update screenshots
    [servo.kicad_pcb]
2026-08-07 Add old pcb photo as placeholder
2026-08-07 Optimize buzzer, add beeping instead of steady tone
    [servo.kicad_sch]
2026-08-07 Add r10 designator
    [servo.kicad_pcb]
2026-08-11 Remove stall demo, clean up, add homing
    [main.c]
2026-08-11 Add powerdown indication
2026-08-18 2 position homing work in progress
2026-08-19 Add two mode homing
2026-08-20 Add enclosure drawing
2026-08-20 Increase mixing speed, add current readout variable
2026-08-22 Add servo cutoff when writing to flash
2026-08-25 Add inductor parameters, add calculation file for 12V-6V conversion
    [servo.kicad_sch, v2.xlsm, v3.xlsm]

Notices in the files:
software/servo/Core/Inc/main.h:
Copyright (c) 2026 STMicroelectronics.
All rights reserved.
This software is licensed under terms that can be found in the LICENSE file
